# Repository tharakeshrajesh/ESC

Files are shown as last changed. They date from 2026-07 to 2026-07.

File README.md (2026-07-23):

# ESC
A probably not working electronic speed controller for a brushless direct current motor. <br>
It is rated for 12V and 20A (probably). <br>
<br>
__IT IS CURRENTLY UNTESTED SO TEST IT AT YOUR OWN WILL.__ <br>
<br>
I recommend reading all the README in each folder. **They are not all the same.**

## Some other info
This is a custom ESC made from scratch including a MOSFET half-bridge meant for brushless DC motors. Switches phases at high speeds. It takes in 12v and 20a from an XT60 male connector. You can program the STM microcontroller using the SWD header pins located on the board. There are two status LEDs (one on each side) to help with debugging if needed. The LED on the back of the board (D1) is connected to the gate driver fault pins so it will turn on if there is an error with the gate driver. The LED on the front (D3) is connected to the STM32 micocontroller and can be programmed for debugging or something (connected to pin 40). There are NO phase pads or bullet connectors located on the board for this revision so you will need to use alligator clips or something on the MOSFET source pins/body.

# Schematics


# PCB Previews





# Contact
email -> trajesh@3272010.xyz

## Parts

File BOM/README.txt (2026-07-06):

I'm too lazy to add anymore LCSC part numbers to the JLCPCB BOM so you will have to do most of them yourself.

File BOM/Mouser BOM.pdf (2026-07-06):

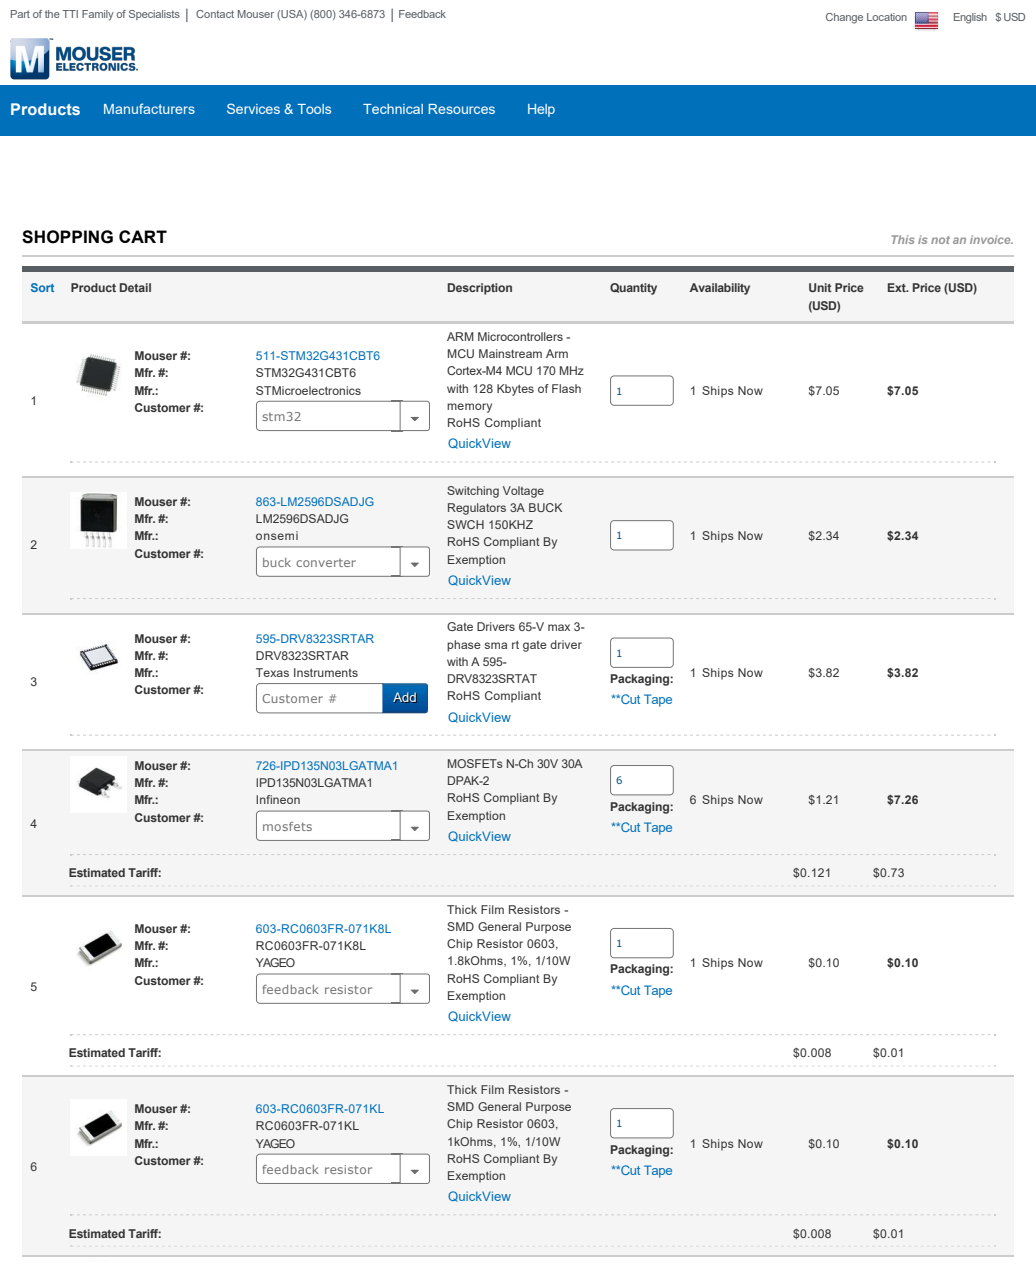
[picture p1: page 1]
Mouser #:; 511-STM32G431CBT6; Mfr. #:; STM32G431CBT6; Mfr.:; STMicroelectronics; Customer #:; 1 Ships Now; 863-LM2596DSADJG; LM2596DSADJG; onsemi; 595-DRV8323SRTAR; DRV8323SRTAR; Texas Instruments; 726-IPD135N03LGATMA1; IPD135N03LGATMA1; Infineon; 6 Ships Now; Estimated Tariff:; 652-SRR1260-680M; SRR1260-680M; Bourns; Sort; Product Detail; Description; Quantity; Availability; Unit Price; (USD); SHOPPING CART; This is not an invoice.; Packaging:; **Cut Tape; stm32; buck converter; Customer #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

Ext. Price (USD)

ARM Microcontrollers
MCU Mainstream Arm
Cortex-M4 MCU 170 MHz
with 128 Kbytes of Flash
memory
RoHS Compliant
QuickView

Switching Voltage
Regulators 3A BUCK
SWCH 150KHZ
RoHS Compliant By
Exemption

Gate Drivers 65-V max 3-
phase sma rt gate driver
with A 595-
DRV8323SRTAT

MOSFETs N-Ch 30V 30A
DPAK-2

Mouser #: 603-RC0603FR-071K8L (https://www.mouser.com/ProductDetail/YAGEO/RC0603FR-071K8L?qs=VU8sRB4EgwDxKwCsGZAeDw%3D%3D) Mfr. #: RC0603FR-071K8L Mfr.: YAGEO Estimated Tariff: | | Thick Film Resistors SMD General Purpose Chip Resistor 0603, 1 1.8kOhms, 1%, 1/10W 1 Ships Now $0.10 $0.10 Packaging: QuickView $0.008 $0.01

6 | Mouser #: 603-RC0603FR-071KL (https://www.mouser.com/ProductDetail/YAGEO/RC0603FR-071KL?qs=VU8sRB4EgwApHsk4rF%2F3zg%3D%3D) Mfr. #: RC0603FR-071KL Mfr.: YAGEO | Thick Film Resistors SMD General Purpose Chip Resistor 0603, 1kOhms, 1%, 1/10W RoHS Compliant By Exemption QuickView | 1 Packaging: **Cut Tape | 1 Ships Now | $0.10 | $0.10

Power Inductors SMD
68uH 20% SMD 1260

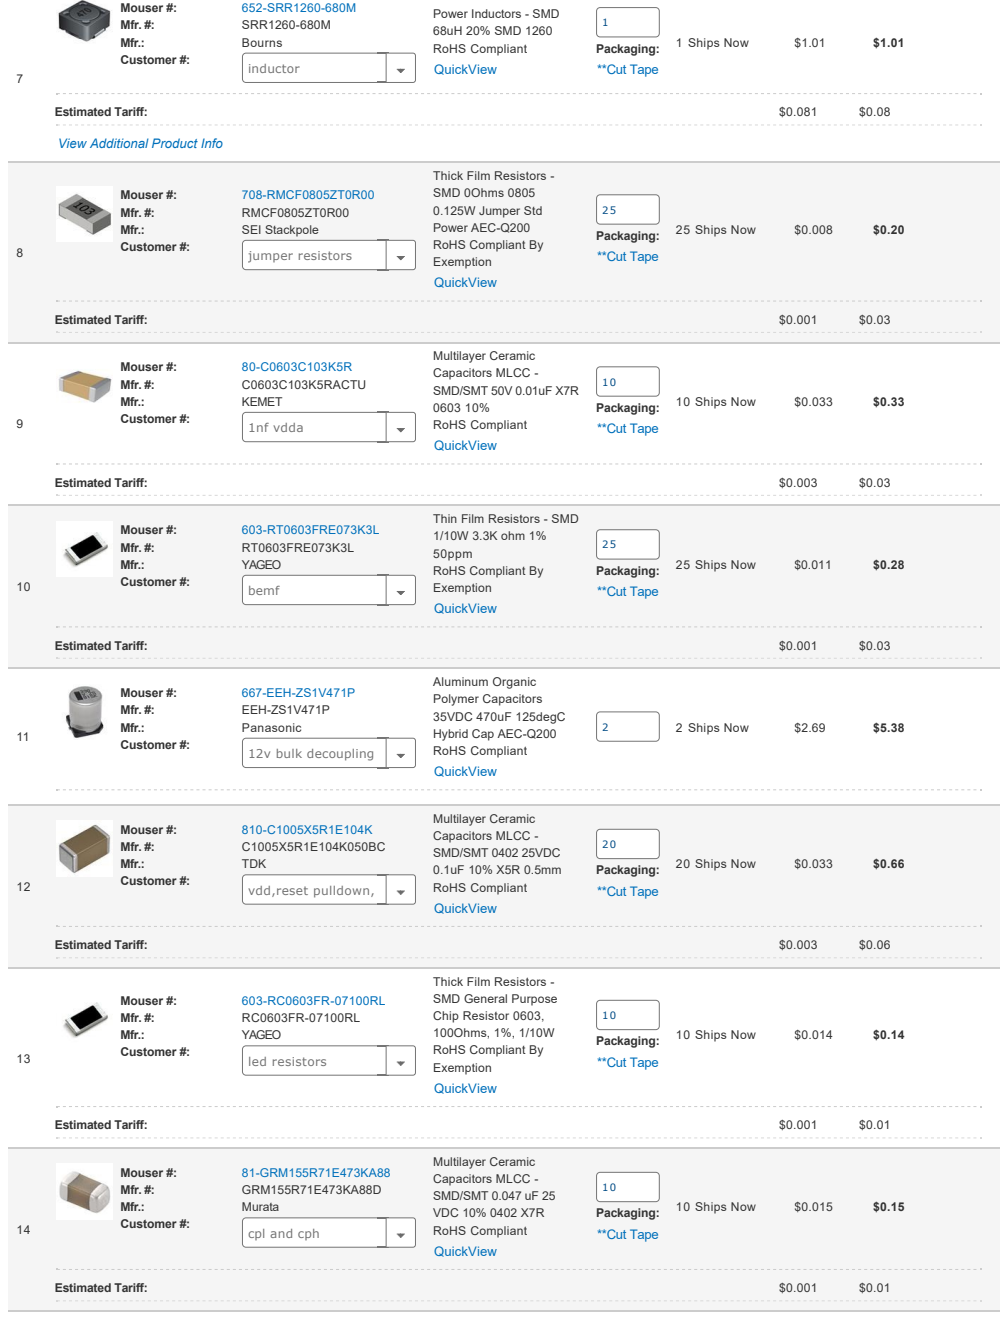
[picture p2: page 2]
Mouser #:; 652-SRR1260-680M; Mfr. #:; SRR1260-680M; Mfr.:; Bourns; 1 Ships Now; Estimated Tariff:; 708-RMCF0805ZT0R00; RMCF0805ZT0R00; SEI Stackpole; Customer #:; 25 Ships Now; C0603C103K5RACTU; KEMET; Multilayer Ceramic; Capacitors MLCC; SMD/SMT 50V 0.01uF X7R; RoHS Compliant; QuickView; 10 Ships Now; 603-RT0603FRE073K3L; RT0603FRE073K3L; YAGEO; 667-EEH-ZS1V471P; EEH-ZS1V471P; Panasonic; 2 Ships Now; TDK; SMD/SMT 0402 25VDC; 20 Ships Now; 81-GRM155R71E473KA88; GRM155R71E473KA88D; Murata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

Power Inductors SMD
68uH 20% SMD 1260

View Additional Product Info

Thick Film Resistors
SMD 0Ohms 0805
0.125W Jumper Std
Power AEC-Q200
RoHS Compliant By
Exemption
QuickView

Thin Film Resistors SMD
1/10W 3.3K ohm 1%
50ppm

Aluminum Organic
Polymer Capacitors
35VDC 470uF 125degC
Hybrid Cap AEC-Q200
RoHS Compliant

vdd,reset pulldown,pg

SMD General Purpose
Chip Resistor 0603,
100Ohms, 1%, 1/10W

Multilayer Ceramic
Capacitors MLCC
SMD/SMT 0.047 uF 25
VDC 10% 0402 X7R

cpl and cph

DFRobot Accessories
High Quality Gold Plated

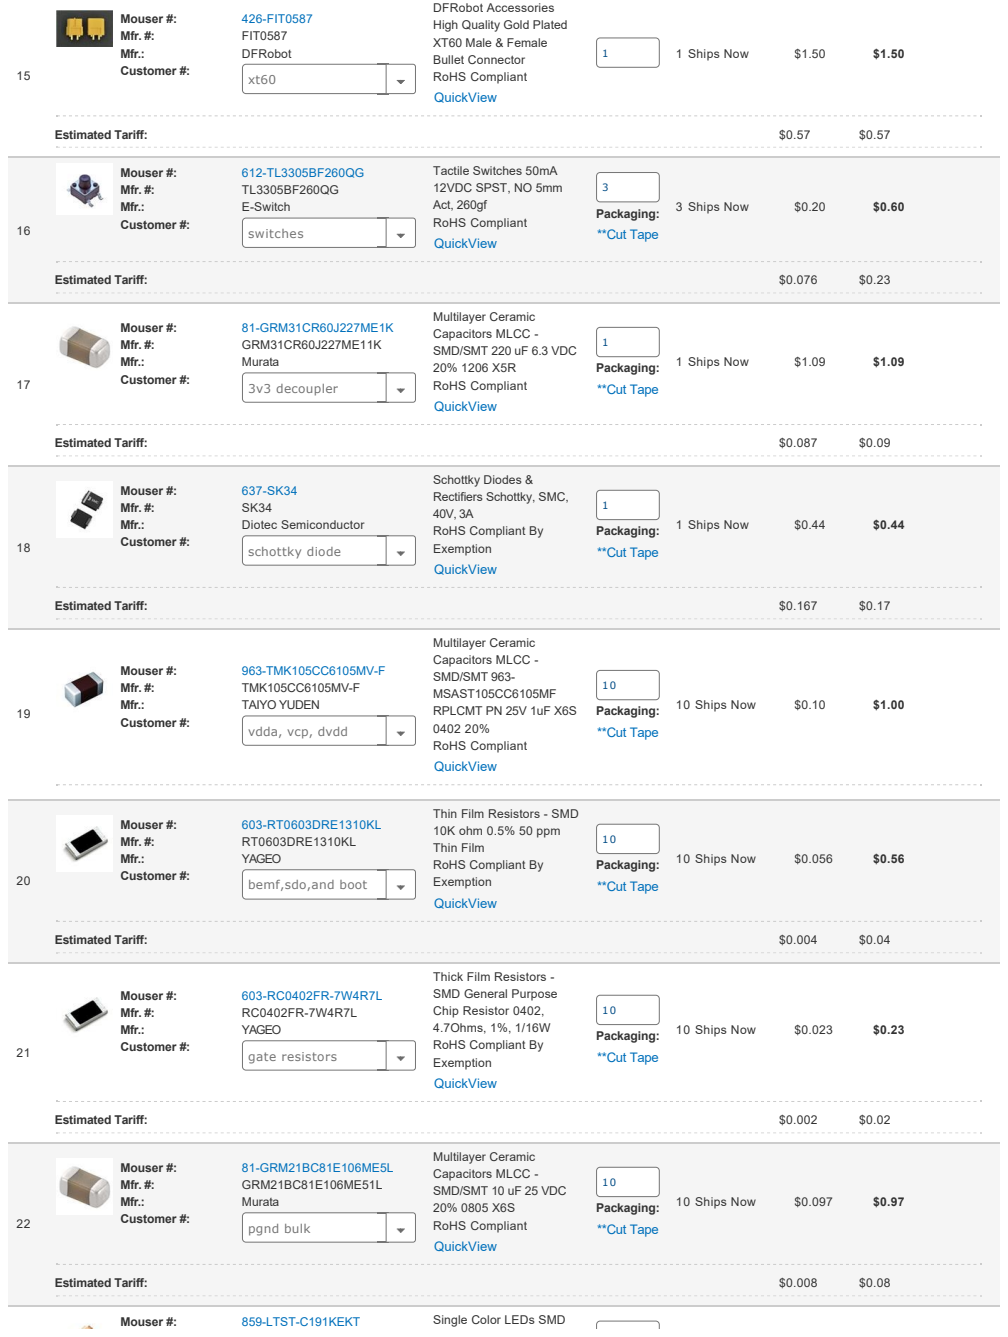
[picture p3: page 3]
Mouser #:; 426-FIT0587; Mfr. #:; FIT0587; Mfr.:; DFRobot; 1 Ships Now; Estimated Tariff:; E-Switch; Customer #:; Tactile Switches 50mA; 12VDC SPST, NO 5mm; Act, 260gf; RoHS Compliant; QuickView; 3 Ships Now; 81-GRM31CR60J227ME1K; GRM31CR60J227ME11K; Murata; Diotec Semiconductor; 963-TMK105CC6105MV-F; TMK105CC6105MV-F; TAIYO YUDEN; Multilayer Ceramic; Capacitors MLCC; SMD/SMT 963-; MSAST105CC6105MF; RPLCMT PN 25V 1uF X6S; 10 Ships Now; 603-RT0603DRE1310KL; RT0603DRE1310KL; YAGEO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

DFRobot Accessories
High Quality Gold Plated
XT60 Male & Female
Bullet Connector

Multilayer Ceramic
Capacitors MLCC
SMD/SMT 220 uF 6.3 VDC
RoHS Compliant
QuickView

Schottky Diodes &
Rectifiers Schottky, SMC,
RoHS Compliant By
Exemption

vdda, vcp, dvdd

Thin Film Resistors SMD
10K ohm 0.5% 50 ppm
Thin Film

bemf,sdo,and boot

Thick Film Resistors
SMD General Purpose
Chip Resistor 0402,
4.7Ohms, 1%, 1/16W

SMD/SMT 10 uF 25 VDC

Single Color LEDs SMD
LED Thin Red 621nm

Mfr. #: | LTST-C191KEKT
Mfr.: | LITEON

LED Thin Red 621nm
60mcd
10 Ships Now | $0.076 | $0.76
Estimated Tariff: | $0.006 | $0.06

View Additional Product Info

By submitting your order you agree to these terms and conditions. (https://www.mouser.com/saleterms) For additional information on availability, click on the Mouser Part #.

**All MouseReel™ items are noncancellable and nonreturnable.

Merchandise: | | $35.97
Shipping: | UPS Ground | $8.49
UPS 2nd Day | $13.99
FedEx 2nd Day | $13.99
UPS Next Day SAVER | $28.99
FedEx Standard Overnight | $28.99
Estimated Tariff: | $2.26
Subtotal: | $46.72

Checkout

Customer # | Add

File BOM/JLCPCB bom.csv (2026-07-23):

Designator | Footprint | Quantity | Value | LCSC Part #
C1, C2 | CAP_ZSU_G16_PAN | 2 | 470µF | C403803
C10 | 0805 | 1 | ≥10µF 25V | C602037
C11, C14, C15, C16, C17, C4 | 0402 | 6 | 100nF | C466234
C12 | 0603 | 1 | 10nF | C100042
C13 | 0402 | 1 | 1µF | C29266
C3 | 1206 | 1 | 220µF | C5357184
C5 | 0402 | 1 | 47nF 25V | C285062
C6 | 0402 | 1 | 1µF 6.3V | C107372
C7 | 0402 | 1 | 1µF 25V | C52923
C8 | 0402 | 1 | 100nF 6.3V | C2176584
C9 | 0402 | 1 | 100nF 25V | C100072
D1, D3 | 0603 | 2 | LED | C19171390
D2 | D_SMC | 1 | SK34 | C260396
J1 | PinHeader_1x02_P2.54mm_Vertical | 1 | SWD Headers
J2 | AMASS_XT60PW-M_1x02_P7.20mm_Horizontal | 1 | XT60 | C98733
J3 | PinHeader_1x02_P2.54mm_Vertical | 1 | SWD Power
L1 | L_Bourns_SRR1260 | 1 | 68µH | C2041353
Q1, Q2, Q3, Q4, Q5, Q6 | TO228P998X235-3N-2-V | 6 | IPD135N03L_G | C152614
R1 | 0603 | 1 | 1.8kΩ | C185354
R10, R11, R12, R7, R8, R9 | 0402 | 6 | 4.7Ω | C2906942
R13, R14, R15, R2, R6 | 0603 | 5 | 10kΩ | C98220
R16, R17, R18 | 0603 | 3 | 3.3kΩ | C2907023
R19, R20, R21 | 0805 | 3 | 0Ω | C17477
R3 | 0603 | 1 | 1kΩ | C2907002
R4, R5 | 0603 | 2 | 100Ω | C2906981
SW1, SW2 | SW_SPST_TL3305B | 2 | SW_SPST | C2886900
U2 | D2PAK-5_ONS | 1 | LM2596DSADJG | C92134
U3 | QFN50P600X600X80-41N415X415 | 1 | DRV8323SRTAT | C2150452
U8 | LQFP48-7x7mm | 1 | STM32G431CBTx | C529355

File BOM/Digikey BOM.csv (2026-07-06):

Index | Quantity | Part Number | Manufacturer Part Number | Description | Customer Reference | Available | Backorder | Unit Price | Extended Price USD
1 | 1 | 497-19473-ND | STM32G431CBT6 | IC MCU 32BIT 128KB FLASH 48LQFP | stm32 | 0 | 1 | 6.01000 | 6.01
2 | 1 | LM2596DSADJGOS-ND | LM2596DSADJG | IC REG BUCK BOOST ADJ 3A D2PAK-5 | buck converter | 1 | 0 | 2.34000 | 2.34
3 | 1 | 296-48535-1-ND | DRV8323SRTAR | IC MTR DRV MULTPHAS 6-60V 40WQFN | gate driver | 1 | 0 | 3.68000 | 3.68
4 | 10 | 4518-IPD135N03LGCT-ND | IPD135N03LG | MOSFET N-CH 30V 30A DPAK | mosfets | 10 | 0 | 0.63600 | 6.36
5 | 10 | 311-1.80KHRCT-ND | RC0603FR-071K8L | RES 1.8K OHM 1% 1/10W 0603 | feedback resistor | 10 | 0 | 0.02500 | 0.25
6 | 10 | 311-1.00KHRCT-ND | RC0603FR-071KL | RES 1K OHM 1% 1/10W 0603 | feedback resistor | 10 | 0 | 0.02500 | 0.25
7 | 1 | SRR1260-680MCT-ND | SRR1260-680M | FIXED IND 68UH 2.1A 110 MOHM SMD | inductor | 1 | 0 | 1.05000 | 1.05
8 | 25 | RMCF0805ZT0R00CT-ND | RMCF0805ZT0R00 | RES 0 OHM JUMPER 1/8W 0805 | jumper resistors | 25 | 0 | 0.00880 | 0.22
9 | 10 | 399-C0603C103K5RACTUCT-ND | C0603C103K5RACTU | CAP CER 10000PF 50V X7R 0603 | 10nf vdda | 10 | 0 | 0.04800 | 0.48
10 | 25 | YAG3354CT-ND | RT0603FRE073K3L | RES SMD 3.3K OHM 1% 1/10W 0603 | bemf | 25 | 0 | 0.01080 | 0.27
11 | 10 | 311-10.0KHRCT-ND | RC0603FR-0710KL | RES 10K OHM 1% 1/10W 0603 | bemf,sdo pulldown,and boot pulldown | 10 | 0 | 0.02500 | 0.25
12 | 2 | P124103CT-ND | EEH-ZS1V471P | CAP ALUMHYB 470UF 20% 35V SMD | 12v bulk cap | 2 | 0 | 2.78000 | 5.56
13 | 10 | 311-4.70LRCT-ND | RC0402FR-074R7L | RES 4.7 OHM 1% 1/16W 0402 | gate resistors | 10 | 0 | 0.02600 | 0.26
14 | 10 | 4713-GMC04X5R105K25NTCT-ND | GMC04X5R105K25NT | CAP0402 X5R 1UF 10% 25V | vdda, vcp, dvdd | 10 | 0 | 0.03300 | 0.33
15 | 20 | 2679-C0402X5R250-104KNP-CT-ND | C0402X5R250-104KNP-CT | CAP CER 0.1UF 25V X5R 0402 | vdd,reset pulldown,pgnd,vref | 20 | 0 | 0.00400 | 0.08
16 | 10 | 490-10748-1-ND | GRM21BR61E106MA73L | CAP CER 10UF 25V X5R 0805 | pgnd bulk | 10 | 0 | 0.09100 | 0.91
17 | 10 | 311-100HRCT-ND | RC0603FR-07100RL | RES 100 OHM 1% 1/10W 0603 | led resistors | 10 | 0 | 0.02500 | 0.25
18 | 10 | 490-3254-1-ND | GRM155R71E473KA88D | CAP CER 0.047UF 25V X7R 0402 | cpl and cph | 10 | 0 | 0.02200 | 0.22
19 | 1 | 1738-1437-ND | FIT0587 | HIGH QUALITY GOLD PLATED XT60 MA | xt60 connector | 1 | 0 | 1.50000 | 1.50
20 | 10 | SML-D12U1WT86CT-ND | SML-D12U1WT86 | LED RED DIFFUSED 1608 SMD | led | 10 | 0 | 0.08400 | 0.84
21 | 3 | EG5354CT-ND | TL3305BF260QG | SWITCH TACTILE SPST-NO 0.05A 12V | switches | 3 | 0 | 0.20000 | 0.60
22 | 1 | 490-GRM31CR60J227ME11KCT-ND | GRM31CR60J227ME11K | CAP CER 220UF 6.3V X5R 1206 | 3v3 decoupler | 1 | 0 | 1.09000 | 1.09
23 | 1 | 4786-SK34CT-ND | SK34 | RECTIFIER, SCHOTTKY, 3A, 40V, DO | schottky diode | 1 | 0 | 0.46000 | 0.46

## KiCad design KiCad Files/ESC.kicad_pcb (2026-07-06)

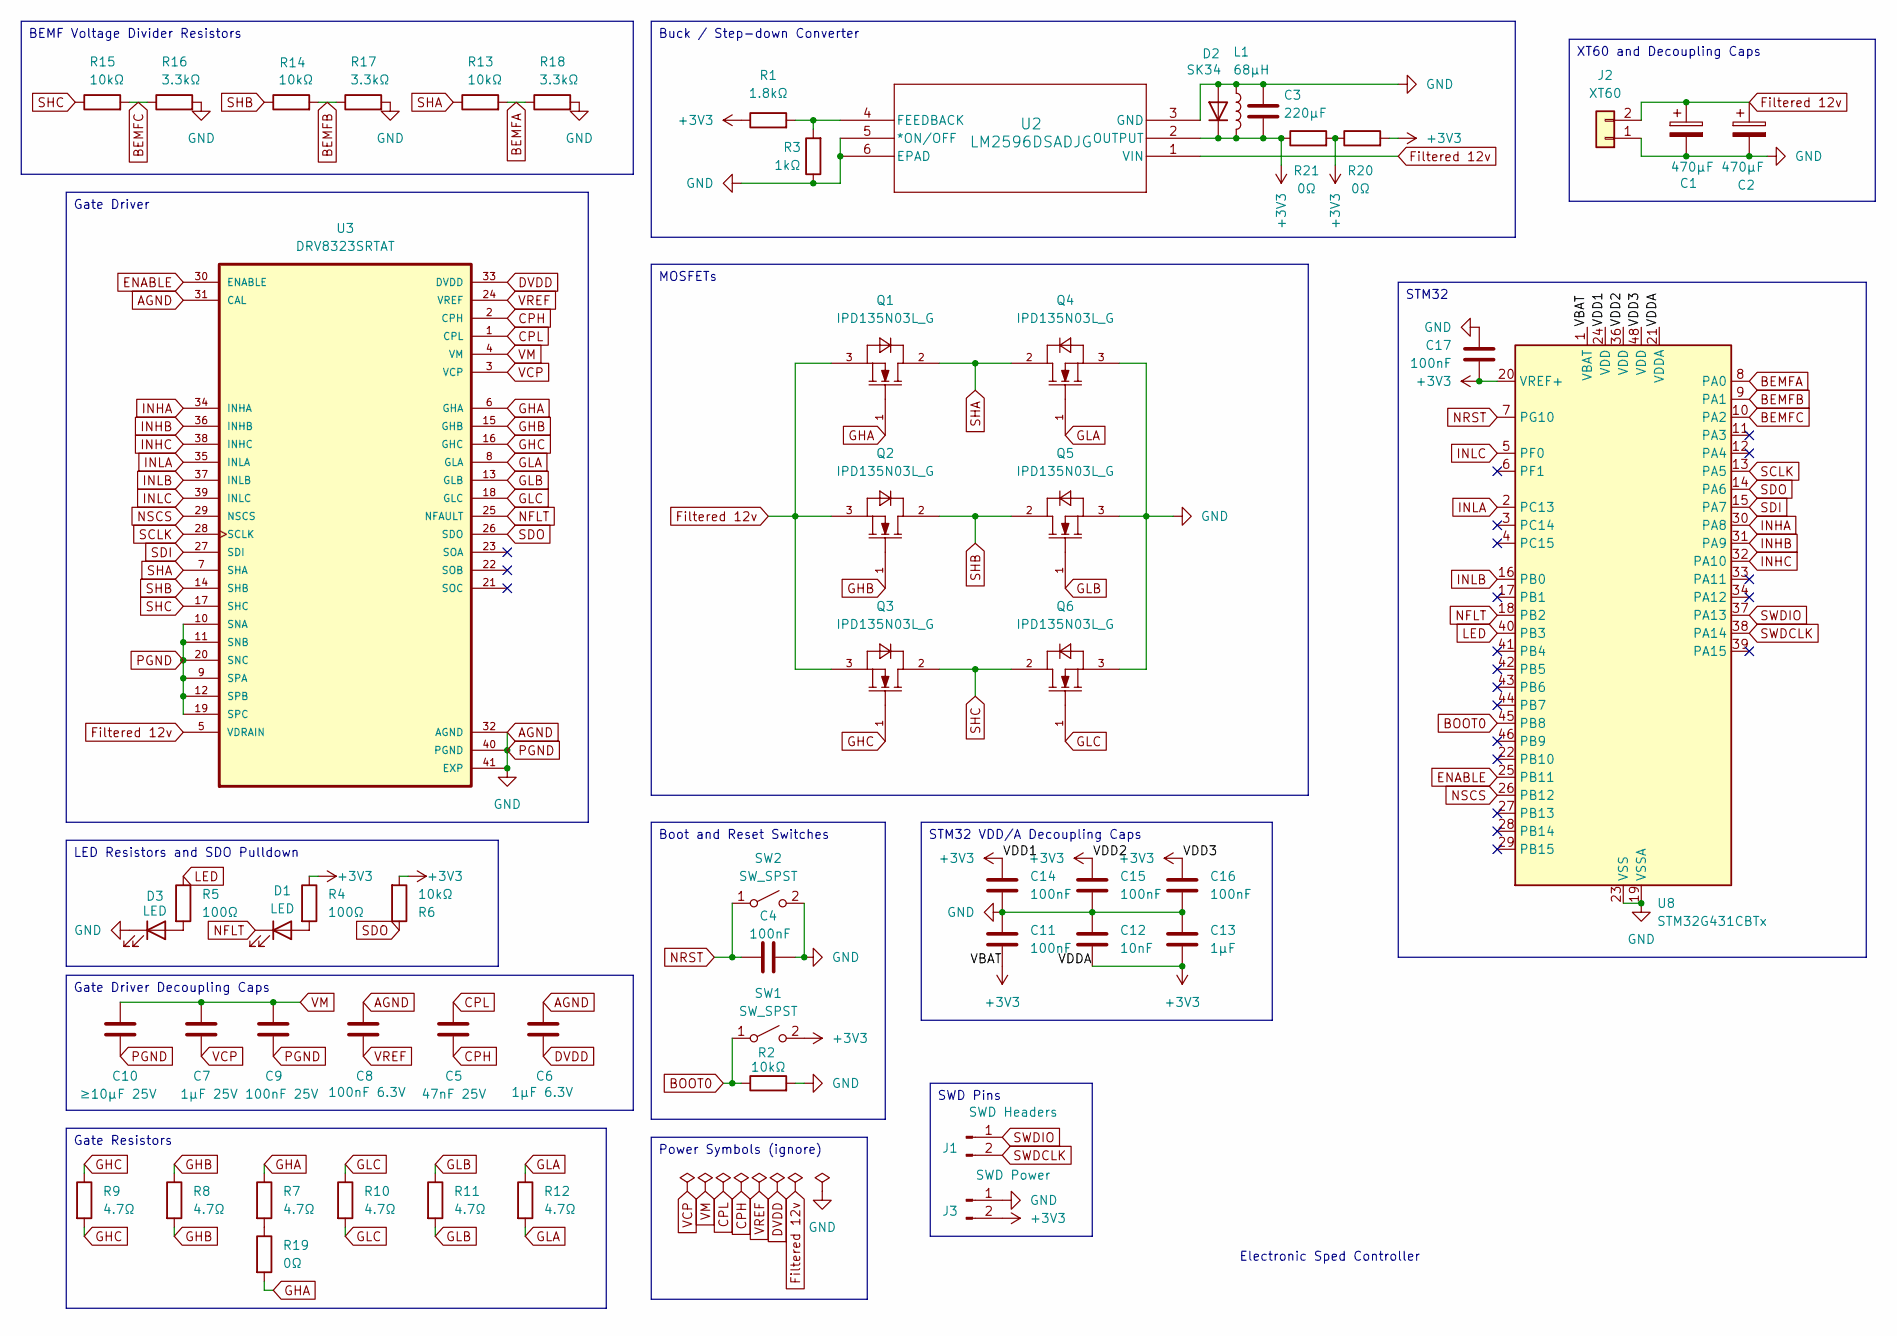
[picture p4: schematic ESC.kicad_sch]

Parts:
C1, C2: 470µF; CAP_ZSU_G16_PAN
C3: 220µF; C_1206_3216Metric
C4, C11, C14, C15, C16, C17: 100nF; C_0402_1005Metric
C5: 47nF 25V; C_0402_1005Metric
C6: 1µF 6.3V; C_0402_1005Metric
C7: 1µF 25V; C_0402_1005Metric
C8: 100nF 6.3V; C_0402_1005Metric
C9: 100nF 25V; C_0402_1005Metric
C10: ≥10µF 25V; C_0805_2012Metric
C12: 10nF; C_0603_1608Metric
C13: 1µF; C_0402_1005Metric
D1, D3: LED; LED_0603_1608Metric
D2: SK34; D_SMC
J1: SWD Headers; PinHeader_1x02_P2.54mm_Vertical
J2: XT60; AMASS_XT60PW-M_1x02_P7.20mm_Horizontal
J3: SWD Power; PinHeader_1x02_P2.54mm_Vertical
L1: 68µH; L_Bourns_SRR1260
Q1, Q2, Q3, Q4, Q5, Q6: IPD135N03L_G; TO228P998X235-3N-2-V
R1: 1.8kΩ; R_0603_1608Metric
R2, R6, R13, R14, R15: 10kΩ; R_0603_1608Metric
R3: 1kΩ; R_0603_1608Metric
R4, R5: 100Ω; R_0603_1608Metric
R7, R8, R9, R10, R11, R12: 4.7Ω; R_0402_1005Metric
R16, R17, R18: 3.3kΩ; R_0603_1608Metric
R19, R20, R21: 0Ω; R_0805_2012Metric
SW1, SW2: SW_SPST; SW_SPST_TL3305B
U2: LM2596DSADJG; D2PAK-5_ONS
U3: DRV8323SRTAT; QFN50P600X600X80-41N415X415; DigiKey_Part_Number 296-47095-1-ND
U8: STM32G431CBTx; LQFP48-7x7mm

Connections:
+3V3: C3.2, C11.2, C12.2, C13.2, C14.1, C15.1, C16.1, C17.1, D2.1 (K), J3.2, L1.2, R1.1, R4.1, R6.2, R20.1, R20.2, R21.1, R21.2, SW1.2 (B), U2.2 (OUTPUT), U8.1 (VBAT), U8.20 (VREF+), U8.21 (VDDA), U8.24 (VDD), U8.36 (VDD), U8.48 (VDD)
AGND: C1.2, C2.2, C3.1, C4.2, C6.1, C8.1, C9.2, C10.2, C11.1, C12.1, C13.1, C14.2, C15.2, C16.2, C17.2, D2.2 (A), D3.1 (K), J2.1, J3.1, L1.1, Q4.3, Q5.3, Q6.3, R2.2, R3.1, R16.2, R17.2, R18.2, SW2.2 (B), U2.3 (GND), U2.5 (*ON/OFF), U2.6 (EPAD), U3.9 (SPA), U3.10 (SNA), U3.11 (SNB), U3.12 (SPB), U3.19 (SPC), U3.20 (SNC), U3.31 (CAL), U3.32 (AGND), U3.40 (PGND), U3.41 (EXP), U8.19 (VSSA), U8.23 (VSS), U8.35 (VSS), U8.47 (VSS)
BEMFA: R13.2, R18.1, U8.8 (PA0)
BEMFB: R14.2, R17.1, U8.9 (PA1)
BEMFC: R15.2, R16.1, U8.10 (PA2)
BOOT0: R2.1, SW1.1 (A), U8.45 (PB8)
CPH: C5.2, U3.2 (CPH)
CPL: C5.1, U3.1 (CPL)
DVDD: C6.2, U3.33 (DVDD)
ENABLE: U3.30 (ENABLE), U8.25 (PB11)
Filtered 12v: C1.1, C2.1, J2.2, Q1.3, Q2.3, Q3.3, U2.1 (VIN), U3.5 (VDRAIN)
GHB: Q2.1, R8.1, R8.2, U3.15 (GHB)
GHC: Q3.1, R9.1, R9.2, U3.16 (GHC)
GLA: Q4.1, R12.1, R12.2, U3.8 (GLA)
GLB: Q5.1, R11.1, R11.2, U3.13 (GLB)
GLC: Q6.1, R10.1, R10.2, U3.18 (GLC)
INHA: U3.34 (INHA), U8.30 (PA8)
INHB: U3.36 (INHB), U8.31 (PA9)
INHC: U3.38 (INHC), U8.32 (PA10)
INLA: U3.35 (INLA), U8.2 (PC13)
INLB: U3.37 (INLB), U8.16 (PB0)
INLC: U3.39 (INLC), U8.5 (PF0)
LED: R5.1, U8.40 (PB3)
NFLT: D1.1 (K), U3.25 (NFAULT), U8.18 (PB2)
NRST: C4.1, SW2.1 (A), U8.7 (PG10)
NSCS: U3.29 (NSCS), U8.26 (PB12)
unnamed: D1.2 (A), R4.2
unnamed: D3.2 (A), R5.2
unnamed: R7.2, R19.1
unnamed: R1.2, R3.2, U2.4 (FEEDBACK)
SCLK: U3.28 (SCLK), U8.13 (PA5)
SDI: U3.27 (SDI), U8.15 (PA7)
SDO: R6.1, U3.26 (SDO), U8.14 (PA6)
SHA: Q1.2, Q4.2, R13.1, U3.7 (SHA)
SHB: Q2.2, Q5.2, R14.1, U3.14 (SHB)
SHC: Q3.2, Q6.2, R15.1, U3.17 (SHC)
SWDCLK: J1.2, U8.38 (PA14)
SWDIO: J1.1, U8.37 (PA13)
VCP: C7.2, U3.3 (VCP)
VM: C7.1, C9.1, C10.1, U3.4 (VM)
VREF: C8.2, U3.24 (VREF)

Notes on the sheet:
Electronic Sped Controller
XT60 and Decoupling Caps
Boot and Reset Switches
SWD Pins
Gate Resistors
STM32 VDD/A Decoupling Caps
STM32
MOSFETs
Buck / Step-down Converter
BEMF Voltage Divider Resistors
Power Symbols (ignore)
Gate Driver Decoupling Caps
LED Resistors and SDO Pulldown
Gate Driver

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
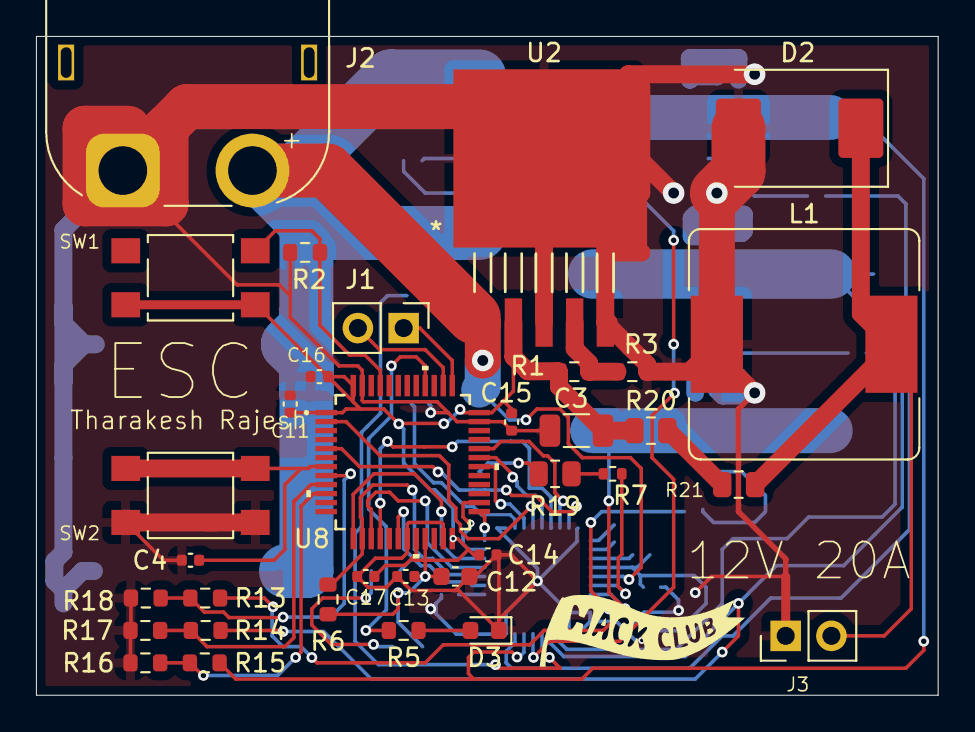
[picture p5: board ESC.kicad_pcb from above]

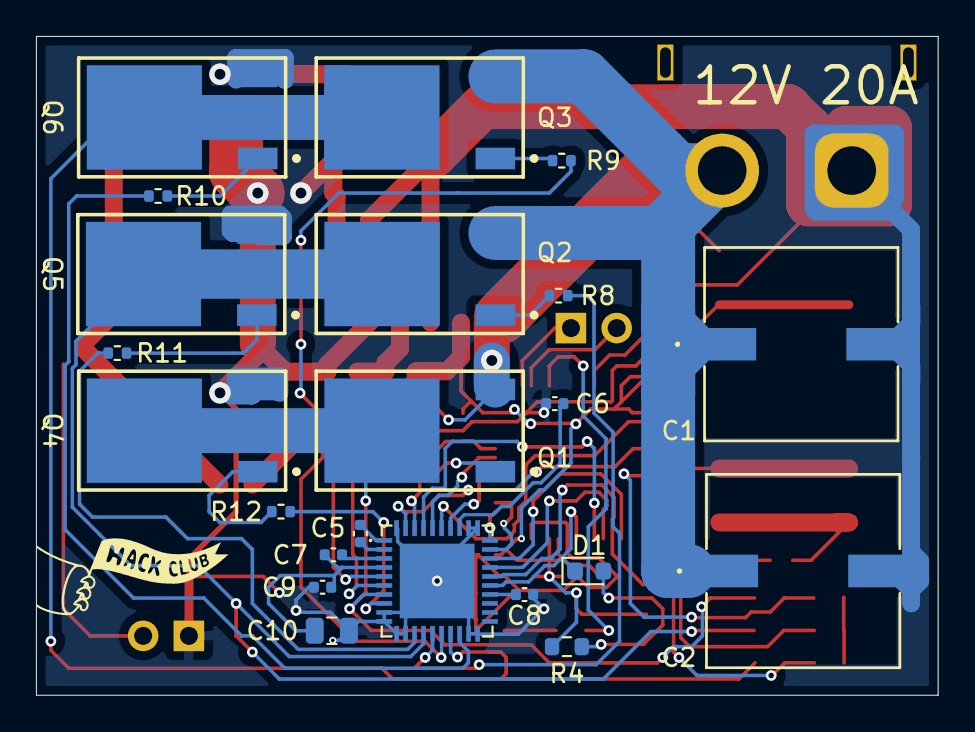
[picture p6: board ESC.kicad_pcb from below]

Board: 2 copper layers, 50.1 x 36.6 mm, 56 parts (22 on the bottom side), 43 nets.

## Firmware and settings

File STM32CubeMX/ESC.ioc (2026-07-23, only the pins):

Mcu.UserName=STM32G431CBTx
PA0.Signal=ADC1_IN1
PA1.Signal=ADC1_IN2
PA10.Signal=S_TIM1_CH3
PA11.Signal=S_TIM1_CH4
PA2.Signal=ADC1_IN3
PA5.Signal=SPI1_SCK
PA6.Signal=SPI1_MISO
PA7.Signal=SPI1_MOSI
PA8.Signal=S_TIM1_CH1
PA9.Signal=S_TIM1_CH2
PB0.Signal=TIM1_CH2N
PB12.Signal=GPIO_Output
PB13.Signal=GPIO_Output
PB2.Signal=GPIO_Input
PB3.Signal=GPIO_Output
PC13.Signal=TIM1_CH1N
PF0-OSC_IN.Signal=TIM1_CH3N

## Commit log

2026-07-06 Added Mouser and Digikey carts
    [2026-07-04T171931.csv]
2026-07-06 Organized files and added fab files
    [2026-07-04T171931.csv, Digikey BOM.csv, ESC.kicad_pcb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]
2026-07-22 Added LCSC parts
    [JLCPCB bom.csv]
2026-07-23 Added STM32CubeMX files, added to README, and fixed part number error
    [JLCPCB bom.csv, bom.csv]
